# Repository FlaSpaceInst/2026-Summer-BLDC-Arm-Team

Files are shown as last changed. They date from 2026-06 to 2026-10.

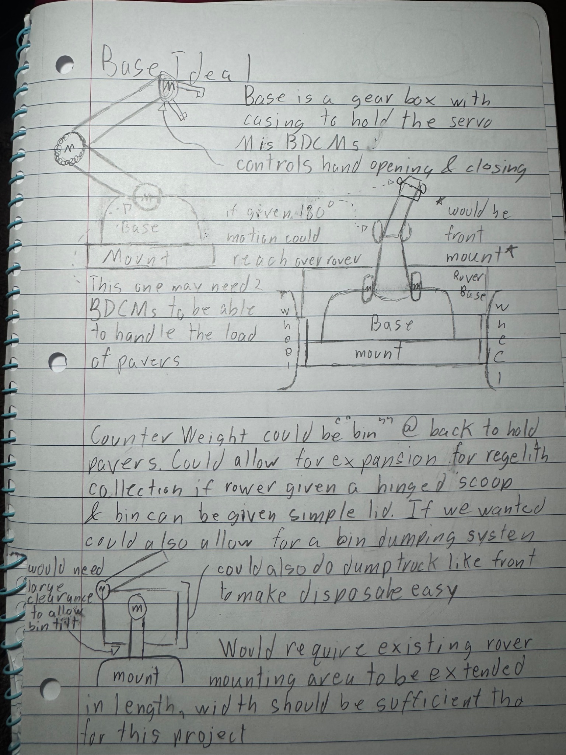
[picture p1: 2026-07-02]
Documentation & Testing/Misc. Design Artifacts/Rover Arm's Preliminary Design Sketch & Notes.jpeg

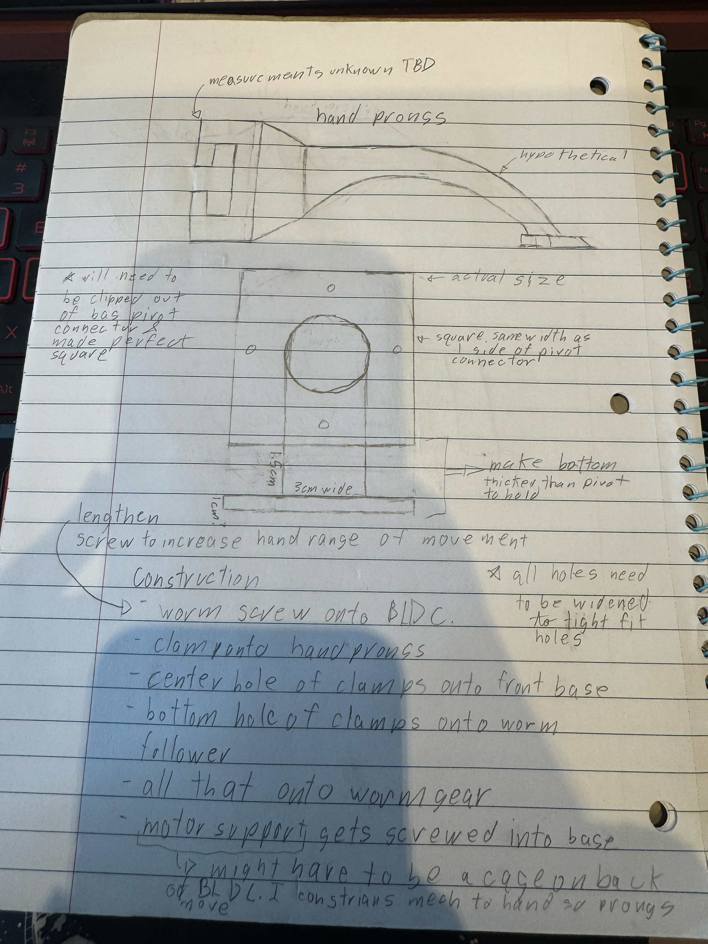
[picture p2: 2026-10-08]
Documentation & Testing/Misc. Design Artifacts/HandModificationEval.jpg

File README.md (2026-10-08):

# RE-RASSOR Arm Development

## Overview

The 2026 RE-RASSOR Arm Development Team is responsible for designing, prototyping, and integrating a modular robotic arm with the existing RE-RASSOR rover platform. The project builds upon previous RE-RASSOR Senior Design efforts while introducing new mechanical, software, and systems engineering capabilities focused on robotic manipulation.

The project has progressed beyond the preliminary design phase and is currently in the implementation, integration, and validation stage. The team has established the arm's primary mechanical architecture, developed and iterated multiple CAD prototypes, integrated inherited rover hardware and software resources, and continued development of the arm control interface and communication architecture.

The current arm design uses a four-degree-of-freedom configuration consisting of a rotating base, shoulder joint, elbow joint, and actuated end effector. The design uses a hybrid actuation approach incorporating a stepper motor for the arm base and BLDC motors for the upper arm joints. The BLDC motor platform builds upon work completed by the 2025 UCF BLDC Motor Control Team and is being evaluated for the different loading conditions introduced by the robotic arm.

Development is being performed iteratively through CAD modeling, additive manufacturing, assembly, subsystem evaluation, software development, and integration. Prototype revisions have been used to identify dimensional, structural, clearance, manufacturing, and assembly issues before progressing toward later versions.

In addition to developing the robotic arm, the project emphasizes documentation, maintainability, and knowledge transfer so future RE-RASSOR teams can continue development using the work produced during the 2026 project cycle.

---

## Project Background

The RE-RASSOR platform is a long-term educational and engineering project maintained through the Florida Space Institute (FSI) and supported by multiple University of Central Florida (UCF) Senior Design teams. The platform has undergone several iterations over multiple years, with each team contributing new capabilities, hardware improvements, software features, and documentation.

The 2026 RE-RASSOR Arm Development Team inherited an existing rover platform, control architecture, electrical systems, software resources, BLDC motor research, and previous design documentation. The current project therefore requires both new development and integration with systems that were not originally created by the 2026 team.

This repository serves as the development repository for the 2026 RE-RASSOR Arm Development Team and contains both inherited project resources and new development work completed during the Summer and Fall 2026 semesters.

---

## Acknowledgements and Prior Work

This project builds upon significant work completed by previous RE-RASSOR teams.

### 2023 RE-RASSOR Extension Team

The rover platform, base cart systems, software architecture, ROS integration, networking components, and core rover functionality contained within the **Base Cart & Control** directory originate primarily from the 2023 RE-RASSOR Extension Team.

Original repository:

https://github.com/FlaSpaceInst/2023-RE-RASSOR-Extension/tree/cart_desktop

The 2026 team did not develop the original rover platform and does not claim authorship of the inherited rover software, control systems, or base vehicle design.

### 2025 UCF BLDC Motor Control Team

The Brushless DC (BLDC) motor research, control systems, CAD resources, motor testing, and supporting documentation contained within the **BLDC CAD** directory originate from the 2025 UCF BLDC Motor Control Senior Design Team.

Original repository:

https://github.com/FlaSpaceInst/2025-Fall-UCF-BLDC-Motor-Control

The 2026 team utilizes this work as a technical reference and foundation for arm actuation development. The 2025 BLDC system was developed primarily for the rover wheel system; the 2026 project is extending its use to the robotic arm and evaluating its behavior under the different loading conditions associated with arm actuation.

The 2026 team does not claim authorship of the original BLDC motor project.

### 2026 RE-RASSOR Arm Development Team

The 2026 Senior Design Team is responsible for:

- Robotic arm design and development
- Arm integration with the existing rover platform
- New CAD models and prototype components
- Arm-related software modifications
- Arm control and user-interface development
- Testing and validation activities
- Documentation generated during the 2026 project cycle
- Future arm control functionality and user interface integration
- Integration of applicable inherited systems into the arm architecture

Unless otherwise noted, materials located within the **Arm & Attachments** and **Documentation & Testing** directories are the work of the 2026 RE-RASSOR Arm Development Team.

---

## Objectives

The primary objectives of this project are:

- Design and develop a robotic arm capable of manipulating the project's standardized 3D-printed pavers.
- Integrate arm controls with the existing RE-RASSOR control architecture.
- Utilize a hybrid stepper/BLDC actuation system appropriate for the arm's mechanical requirements.
- Prototype, evaluate, and iteratively improve the arm's mechanical components.
- Maintain compatibility with existing rover mechanical, electrical, and software systems.
- Develop an operator interface appropriate for multi-joint arm control.
- Establish testing procedures for mechanical, software, electrical, and integrated system evaluation.
- Maintain clear and reproducible project documentation.
- Produce deliverables that can be continued and expanded by future RE-RASSOR teams.

---

## Repository Organization

This repository contains inherited project resources as well as new development work produced during the 2026 project cycle.

### Base Cart & Control

Contains inherited rover resources originating primarily from previous RE-RASSOR teams, including:

- Rover software
- Control architecture
- Existing rover documentation
- Networking resources
- Base platform reference materials

Primary source:

https://github.com/FlaSpaceInst/2023-RE-RASSOR-Extension/tree/cart_desktop/ezrassor_rover/ros-scripts

### BLDC CAD

Contains inherited resources from the 2025 BLDC Motor Control Team, including:

- BLDC motor documentation
- Motor control research
- CAD resources
- Testing documentation
- Related design files

Primary source:

https://github.com/FlaSpaceInst/2025-Fall-UCF-BLDC-Motor-Control

### Arm & Attachments

Contains original development work produced by the 2026 RE-RASSOR Arm Development Team, including mechanical design, prototype development, manufacturing resources, and supporting documentation for the robotic arm.

#### CAD Files

Contains CAD resources developed throughout the project lifecycle.

**End Effector Designs**
- Gripper concepts
- End effector assemblies
- Attachment mechanisms
- Supporting design iterations

**STL & Development Files**
- Native CAD models
- Assembly files
- Prototype development resources
- Editable design files

**G-code & Printing Files**
- Printable STL exports
- Slicer projects
- G-code generated for prototype fabrication
- Manufacturing resources

### Documentation & Testing

Contains documentation produced throughout the project lifecycle, including:

- Design reports
- Design requirements and trade studies
- Testing procedures
- Validation results
- Meeting notes where applicable
- Research summaries
- Sponsor deliverables
- Development and integration documentation
- Records of design revisions and identified limitations

---

## Current Development Status

The project has progressed from preliminary design into active implementation and integration.

The primary mechanical architecture has been established as a four-degree-of-freedom robotic arm consisting of a rotating base, shoulder joint, elbow joint, and actuated end effector. Multiple prototype components have been modeled and fabricated through iterative CAD and additive-manufacturing processes. Prototype evaluation has identified and informed revisions involving dimensional accuracy, mounting interfaces, clearance, alignment, structural geometry, and manufacturability.

The arm's mounting system and base components have undergone multiple design iterations. The end effector has also undergone significant redesign following issues encountered during early prototype fabrication and assembly. These iterations are being retained as part of the project's engineering record to document both successful and unsuccessful design approaches.

Software development is progressing alongside the mechanical implementation. The team is extending the existing rover HTTP, ROS2, serial communication, and microcontroller architecture to support arm-specific commands while preserving existing rover functionality. Development of the arm user interface is also underway, including joint-level controls, arm visualization, camera integration concepts, and safety-oriented interaction mechanisms.

Current development efforts are focused on:

- Refining and fabricating mechanical prototype components
- Integrating the arm mounting system with the rover
- Evaluating the inherited BLDC motor platform under arm-specific loading conditions
- Completing arm communication and control pathways
- Developing and refining the robotic arm user interface
- Establishing reliable subsystem interfaces
- Performing mechanical, software, and integrated testing
- Documenting prototype failures, design revisions, and testing results
- Preparing the system for final validation

Some planned capabilities, including computer-vision-assisted target identification, ArUco-based target tracking, autonomous or semi-autonomous paver retrieval, interchangeable end effectors, and additional arm functionality remain future development priorities rather than completed baseline capabilities.

The remaining development effort will focus on subsystem integration, iterative testing, corrective design changes, and final system validation. Results from this work will be documented for continued development by future RE-RASSOR teams.

---

## License and Attribution

This repository contains a combination of inherited work from previous RE-RASSOR teams and original work created by the 2026 RE-RASSOR Arm Development Team.

Where possible, original sources have been referenced and credited. Users should review the source repositories and any associated licensing information before redistributing inherited materials.

Additional external design references used during development are documented in the project design documentation, including their applicable attribution and licensing requirements.

For questions regarding ownership or attribution of specific resources, consult the original repositories and source documentation referenced by this project.

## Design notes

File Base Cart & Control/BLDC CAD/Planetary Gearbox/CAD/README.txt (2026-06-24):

Gear Ratio: 3.76:1
CoPrime gear teeth numbers
custom 30 degree pressure angle

the purpose of using coprime teeth numbers and the steeper pressure angle is because these gears are intended for 3d print use, and both of these features have a measureable impact on the lifespan of 3d printed gearboxes.

Created by Nick Bernhoft in 2026

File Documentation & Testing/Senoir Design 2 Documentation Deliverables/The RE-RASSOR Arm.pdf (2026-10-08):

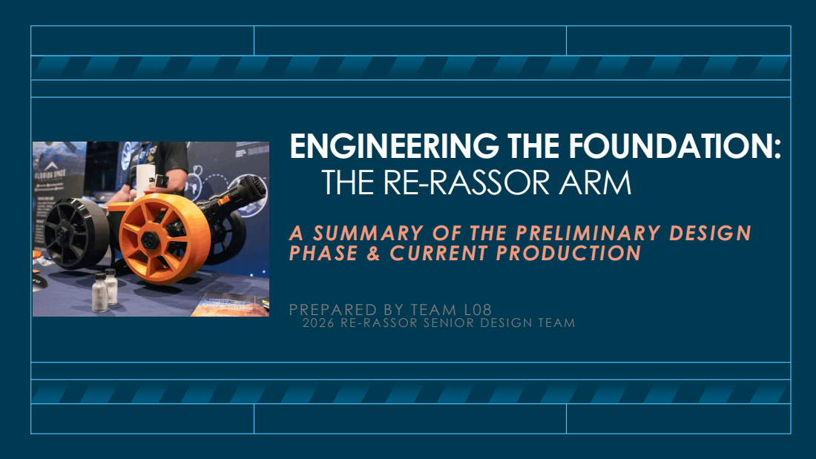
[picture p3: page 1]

ENGINEERING THE FOUNDATION:
THE RE-RASSOR ARM

A SUMMARY OF THE PRELIMINARY DESIGN
PHASE & CURRENT PRODUCTION

PREPARED BY TEAM L08
2026 RE-RA SSOR SE NI OR DE SI GN T E AM

2

Max | Tolu | Kaitlyn | Lucas | Nam
CAD Dev | CAD Dev | Project Manager | Software Dev | Software Dev

Responsibilities:
- Jira & Schedule
Management
- Assisting with CADing the center part of the arm &
counterbalance system +
printing responsibilities
- Initial Stretch Goal
Analysis

Responsibilities:
- Coding HTTP
Requests for the arm
- Integrating new
requests with
preexisting rover
control systems

Responsibilities:
- Coding the UI & API
for the arm
- Integrating new UI &
API with preexisting
rover control systems

Responsibilities:
- Designing &
CADing the arm's
base and
connection
mechanisms to the
existing rover
- Printing & Assembly
of Components

Responsibilities:
- Designing & CADing
the arm's end
effector and
grabbing mechanism
for the arm
- Printing & Assembly
of Components

Sponsored by The Florida Space Institute Funded by the Steven Hawking Center for Microgravity Research

# MEET THE TEAM

Problem 1:

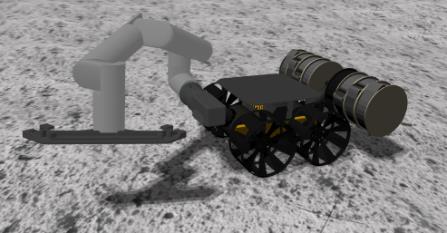
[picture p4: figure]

The Florida Space Institute is exploring 3D printing space craft and that requires initial prototypes to prove feasibility. Previous arm attempts have proven unsuccessful due to structural failure from heavy components and failed to mount onto the rover chasses.

Problem 2:

Due to the longevity of this project the documentation is scattered among 12 repositories and there is no singular source for all current working components.

3

# PROBLEM STATEMENTS

- Design a lightweight, modular robotic arm capable of manipulating standardized 3D-

printed pavers based off of our rover arm's of similar scale and function utilizing the

lighter brushless DC motor.

- Extend the existing software architecture through HTTP-based arm controls without

disrupting the rover's current control system.

- Produce comprehensive engineering documentation to support long-term

maintainability and knowledge transfer to future development teams.

- Organize as much of the existing documentation into our repository and the new

Florida Space Institute Onshape account to allow subsequent teams to pick up where

we left off

4

# OUR SOLUTION

- The Robotic Arm: must be mechanically capable of targeting, lifting, moving, and

precisely positioning the project's standard 3D printed pavers.

- Fully Realized 3D Assembly Models: STEP and .STL files detailing every link, joint,

bracket, and gear assembly of the robotic arm.

- Assembly Instructions: Step by step documentation detailing physical assembly,

fastener sizing, wire routing constraints, and maintenance requirements.

- Extension of Existing Software Architecture: Utilize the existing HTTP Request

architecture to allow our arm to be controlled by similar logic to the drivetrain

5

# REQUIREMENTS

Hardware:

- Printing Materials: PLA, PETG, Bambu X1-Carbon Printer
- Rover Components: BLDC/Stepper motors, Le Potato, Arduinos, BL Cooling Fan, Power Switch, 12.8V Battery, ArduCam
- Other Material Components: Netgear Router, Laptops

Software:

- Production: GitHub/Git, Arduino IDE, Android Studio, Visual Studio
- Libraries & Language: JavaScript, React, HTML, CSS, C++, Python
- CAD & Printing Software: Onshape, AutoCAD, Fusion 360, Bambu Studio

6

# TECH STACK

# THE DEVELOPMENT PLAN

Physical Rover Plan

- Discover failure points of the arms to figure out the core

design of our rover

- Front end designs and prints version 1 of arm in PLA. Then

tests and fixes our major failure points.

- Version 2 (where the project is currently at) is developed

and printed with PLA and final fixes are made after testing

- Final arm is printed in PETG & make final fixes

Software Plan

- Condense the previous 12 GitHub Repositories to get the

scope of the current HTTP request and UI design

- Requests and UI are designed simultaneously to the physical

rover and tested where possible on the prototypes

7

# THE JIRA

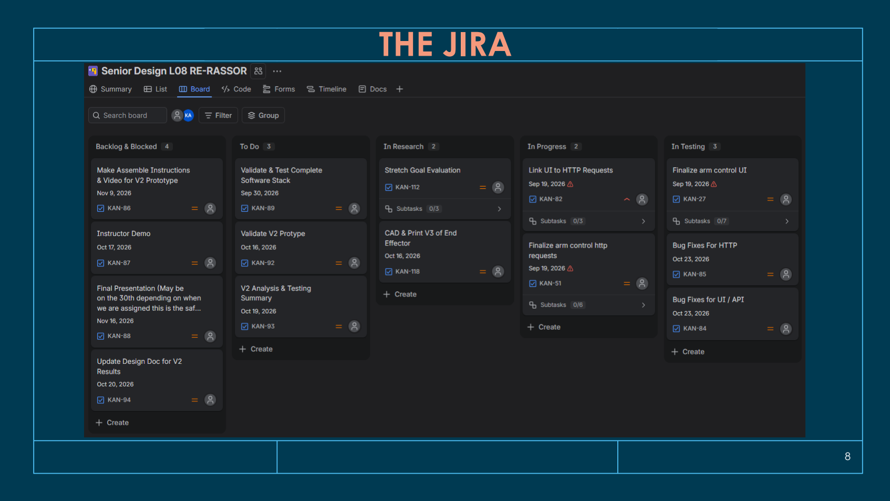
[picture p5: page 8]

8

# USE CASE DIAGRAM

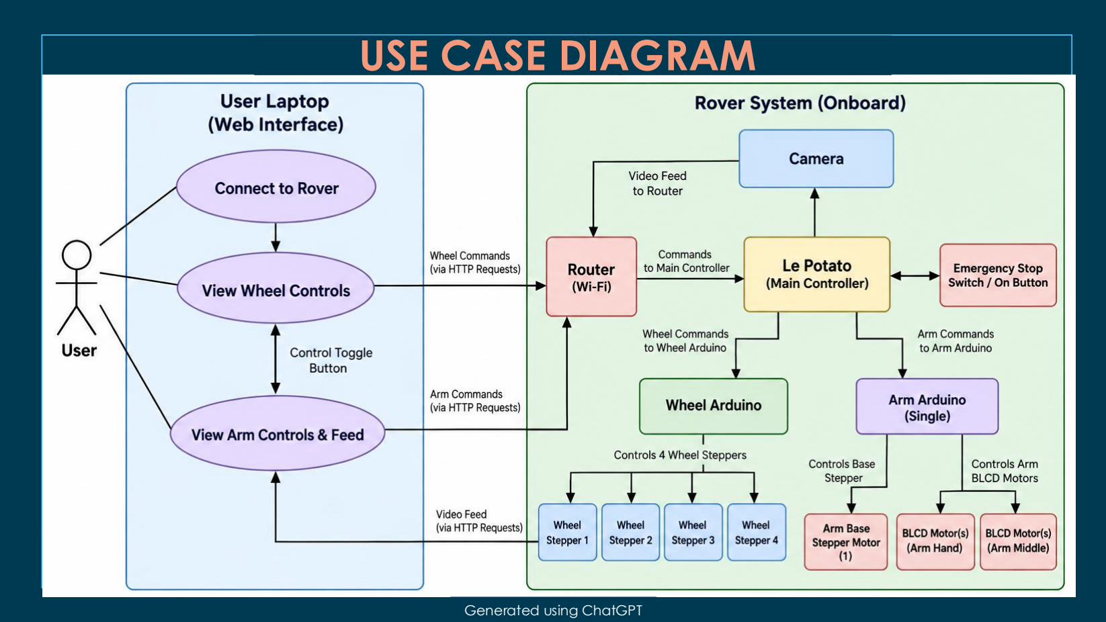
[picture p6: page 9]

9

Generated using ChatGPT

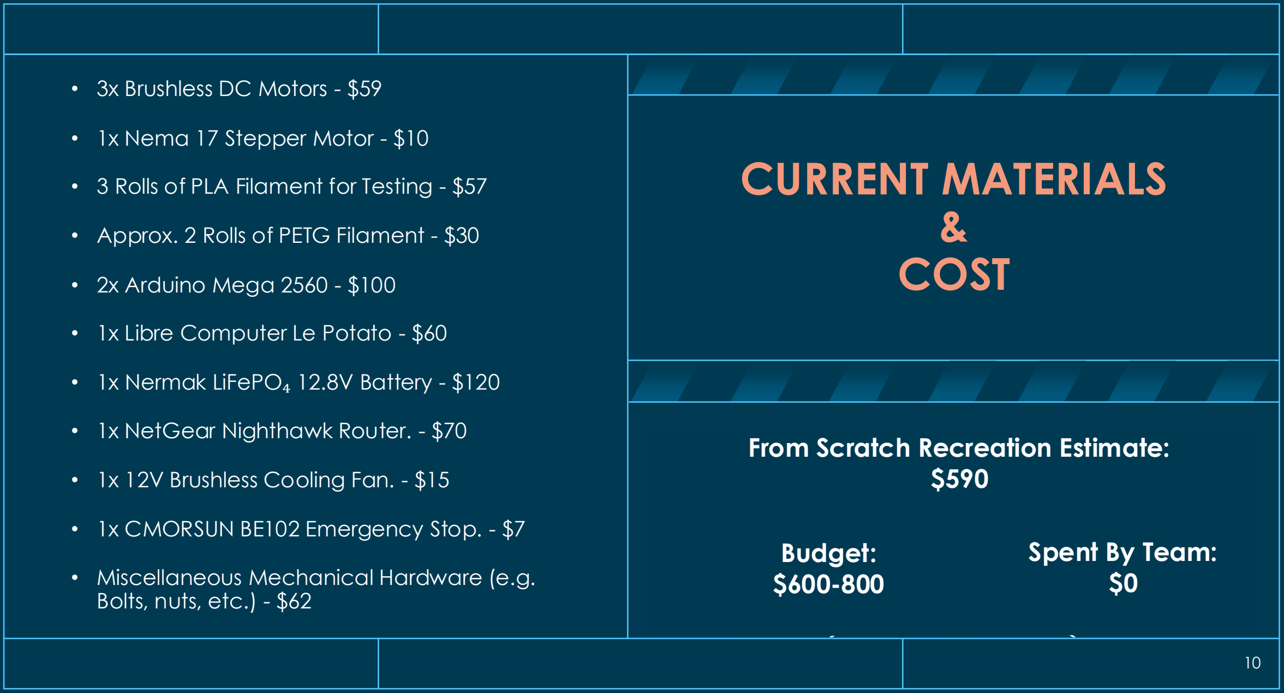
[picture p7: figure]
CURRENT MATERIALS & COST; • 3x Brushless DC Motors - $59; • 1x Nema 17 Stepper Motor - $10; • 2x Arduino Mega 2560 - $100; • 1x Libre Computer Le Potato - $60; • 1x NetGear Nighthawk Router. - $70; • 1x 12V Brushless Cooling Fan. - $15; • 1x CMORSUN BE102 Emergency Stop. - $7; • Miscellaneous Mechanical Hardware (e.g. Bolts, nuts, etc.) - $62; Spent By Team: $0; From Scratch Recreation Estimate: $590; Budget: $600-800

- 3 Rolls of PLA Filament for Testing - $57
- Approx. 2 Rolls of PETG Filament - $30
- 1x Nermak LiFePO₄ 12.8V Battery - $120

DESIGN | DECISION | MATRIX

11

Design Decision | Alternatives | Engineering
Considerations | Final Selection
Actuation | Stepper / Servo / BLDC | Weight, torque, integration, efficiency

## Majority BLDC With a Stepper Base

Arm Location | Front / Rear / Center Mount | Stability, workspace,
compatibility | Front
Communication HTTP / Serial / ROS | Existing infrastructure,
simplicity | HTTP
Printing Material | PETG / PLA | Cost, safety, heat resistance

## PETG for Final PLA to Test

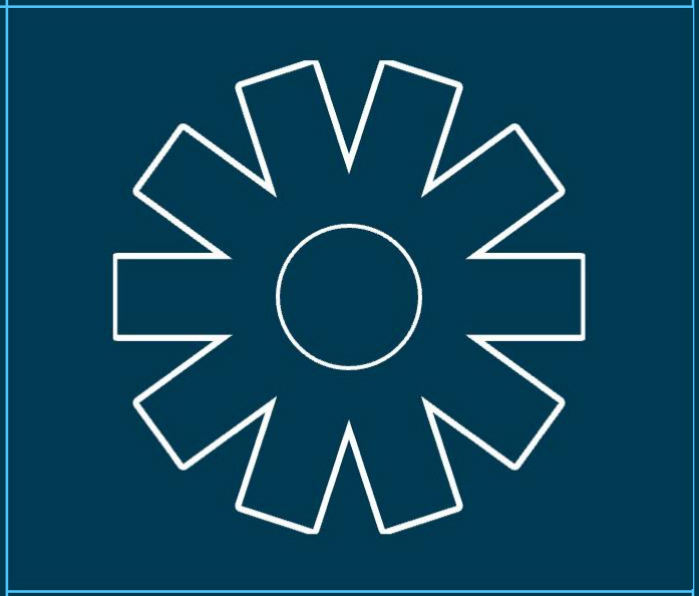
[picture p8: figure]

# OUR STATUS REPORT & SUCCESSES

- The central part of the arm is complete and thus far appears to work with the brushless DC motors upon physical manipulation
- The base of the arm is nearly complete with minimal changes needed
- Final initial CAD mock up of the arm is complete and in printing/testing
- The current printed and assembled components have no weight conflicts with the rover resulting in smooth on-rover assembly
- HTTP requests have been drafted and are in testing
- UI is complete with API being developed

12

# THE CURRENT ROVER

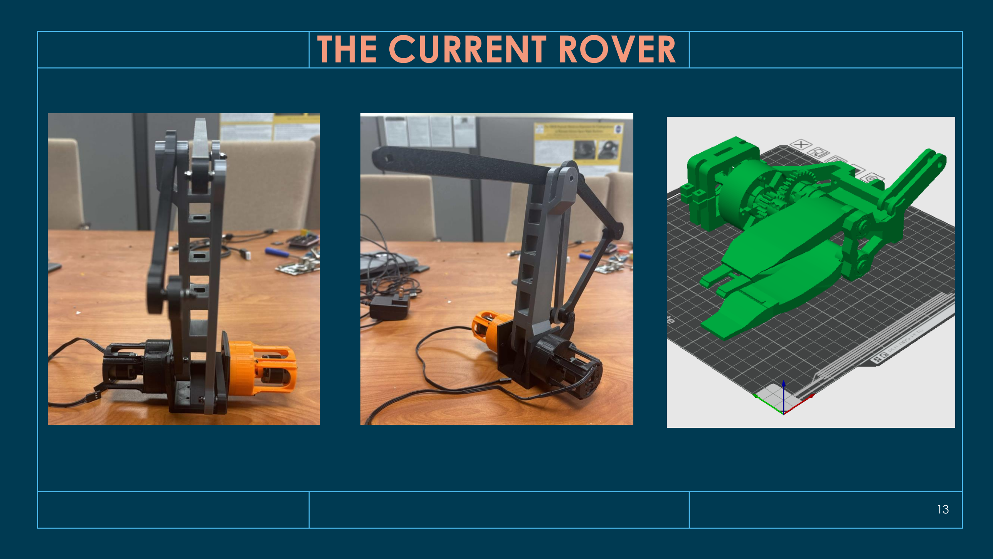
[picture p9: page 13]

13

14

# CURRENT UI

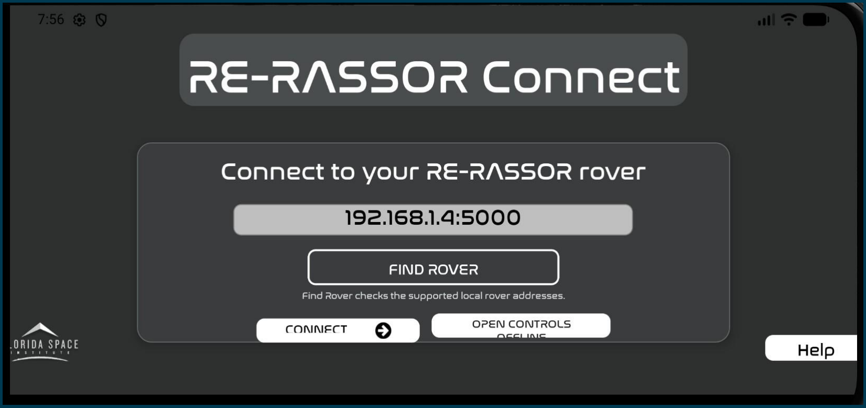
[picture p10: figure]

15

CURRENT UI CONT.

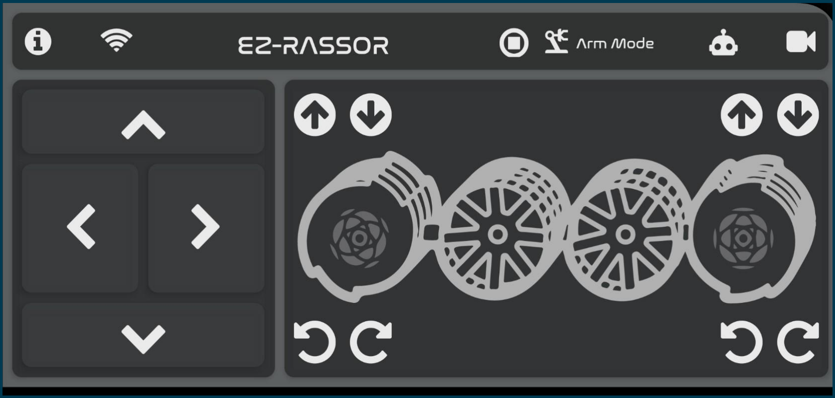
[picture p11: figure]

CURRENT UI CONT.

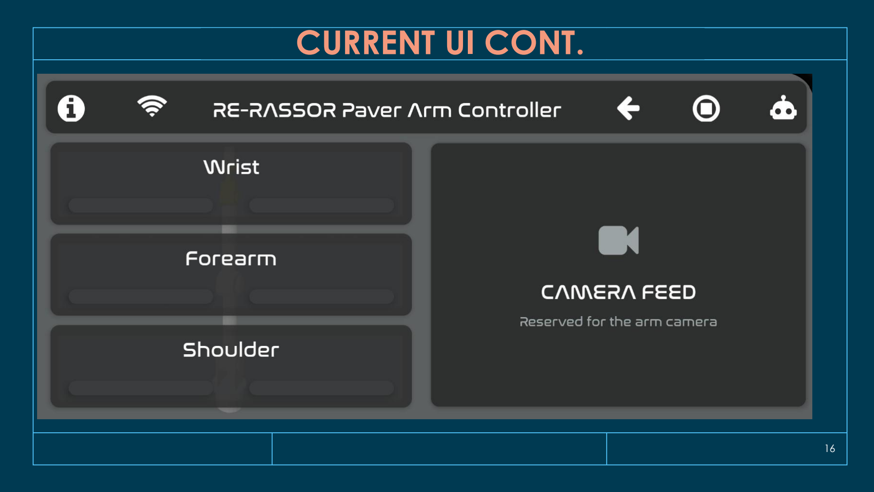
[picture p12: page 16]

16

CURRENT | HTTP | REQUESTS
- The current system has 2 major forms that commands can take on while being passed around:
- HTTP messages containing JSON stringified objects
- Enumerations
- Enumerations are primarily used within the Potato and Arduinos on the rover, while HTTP messages and the corresponding JSON objects are primarily used by the control app to communicate with the rover.
- For example, if the operator chooses to stop the end effector, the corresponding JSON object would be stringified as "{'end_effector_action':'STOP'}" and would be posted to the rover in its own HTTP message.
- This would correspond to the STOP_EFFECTOR command, enumerated as hexadecimal byte 0x0B.

17

18

## - The end effector has been complex to design and thus has taken longer to develop than expected

## - Overall project complexity was more difficult than expected with a primarily software foundation on hardware project

- Lack of documentation resulted in a steep learning curve for any existing rover features

## and resulted in initial development delays

## - A variety of communication styles and personalities has made organizing and communicating difficult and required a learning curve

# OUR CHALLENGES

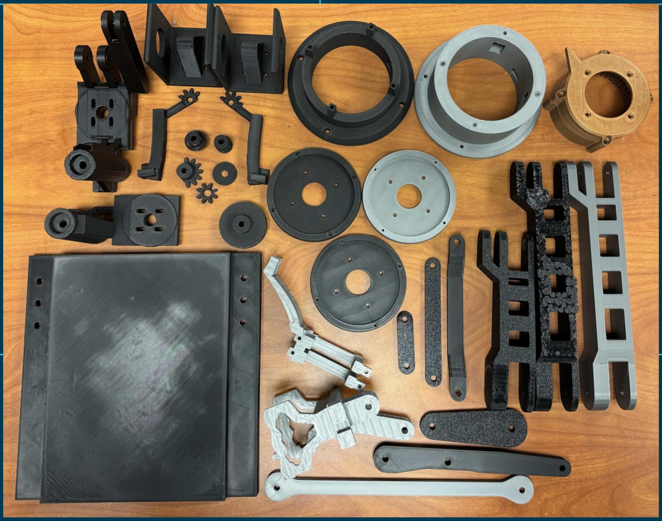
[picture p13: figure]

# THE FAILED PROTOTYPES

Common Causes of Error Include:

- Changes to V2 that resulted in multiple components needing redesign
- Incorrect supports leading to printing issues and difficult to remove components that required redesign
- The printer warping screw holes making exact mechanical connections require multiple adjustments

19

# TOP STRETCH GOALS

- Feasibility Exploration Status: Complete
- Dev / Code Location: PM Branch
- Description:
- Rover uses the Ultralytics YOLO26 Nano
(YOLO26n) model for preliminary item search via the camera and a combination Lucas-Kanade + Canny Algorithm for target tracking after item selection

20

Semi-Autonomous
Item Identification & Retrieval
- Feasibility Exploration Status: To Be Assigned &Complete
- Dev / Code Location: Main / Relevant Member's Branch
- Description:
- Some lunar rover tasks such as regolith collection are not possible with our base rover arm designs. Interchangeable options would enable future teams to build off our work.

Interchangeable End Effectors

# QUESTIONS?

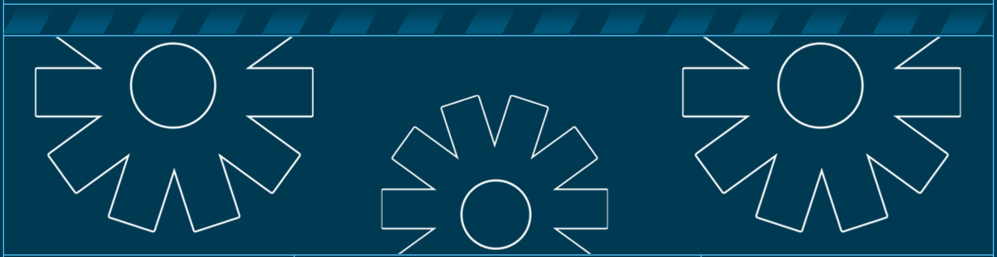
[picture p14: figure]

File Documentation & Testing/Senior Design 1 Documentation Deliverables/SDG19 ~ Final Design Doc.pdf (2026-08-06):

# RE-RASSOR 2026

# Design Document

### Prepared by Group 19:

Kaitlyn Armstrong, Nam Dang, Toluwalope Elugbaju,

Max Grabov, & Lucas Marrou

### Sponsored by the Florida Space Institute

### Funded by the Stephen Hawking Center for Microgravity Research

### University of Central Florida

Department of Computer Science – Senior Design 1 – Summer 2026

Submitted: August 2, 2026

## 2026 RE-RASSOR Final Design Document

# Table of Contents

Management Considerations | 65 Initial Feasibility Analysis | 65 Initial Considerations of Stretch Goals & Feasibility | 66 Autonomous Object Pickup | 66 Additional Wrist Joint for Rotation | 67 Interchangeable End Effector Attachments | 67 Camera Integration into End Effector | 68 Complex Counterweight System | 69 User Interface Design Alterations for Precise Control | 69 Strech Goal Prioritization | 72 Suggested Long-Term Development Roadmap | 73 For More Information on Our Considerations of Users During Our Design See the Administration Section of this Document | 74 Design Diagrams & Descriptions | 75 Use Case Diagram | 75 Activity Diagram | 76 Block Diagram | 77 Component Modifications Made During Development | 78 The Mounting Plate | 78 The Arm Base | 79 The Arm Base Pivot Connector | 82 Planned Modifications to the User Interface | 84 Conclusions | 87 Where We Fell Short | 87 Initial Timeline Issues | 87 Administration | 88 Budget & Material Procurement | 88 Current Cost Breakdown | 89 Arm Cost Table | 89

Rover Body Cost Table | 89 Printing Time Breakdown | 90 User Stories | 91 Rover Operator from a User Perspective | 91 Rover Operator from a System Administrator Perspective | 92 Future RE-RASSOR Development Team | 92 FSI Sponsor | 92 Development Team Member | 93 Researcher | 93 Summary of Current Completed Tasks and Subtasks | 93 Jira Workflow | 95 Acknowledgements | 96 Project Guidance | 97 Institutional Resources | 97 Appendix | 98 Previous RE-RASSOR Projects | 98 Internal Documentation | 98 Hardware Documentation | 99 Software Documentation | 99 Design Inspiration | 100 Robotics & Technical References | 100 Manufacturer Datasheets | 101 Project Methodology | 101

# Executive Summary

The RE-RASSOR Arm Development project is a collaborative senior design effort sponsored by

the Florida Space Institute (FSI) to expand the capabilities of an existing RE-RASSOR rover platform

through the design, fabrication, and integration of a robotic manipulator. Previous iterations of the rover

have successfully demonstrated autonomous mobility and excavation capabilities; however, the platform

currently lacks a manipulator capable of interacting with its environment. The objective of this project is

to develop a multi-degree-of-freedom robotic arm that can be mechanically integrated with the existing

rover while utilizing the current software architecture and communication framework.

The project encompasses the complete engineering design process, including mechanical design,

additive manufacturing, software development, electrical integration, and system testing. Mechanical

components are being modeled using AutoCAD and fabricated through additive manufacturing to enable

rapid prototyping and iterative refinement. Existing rover hardware and software are being leveraged

whenever possible to minimize redevelopment while maintaining compatibility with the established

control system. The software architecture will be extended through additional HTTP-based

communication interfaces that allow independent control of each arm joint while preserving the modular

design of the current rover application.

To reduce technical risk, the project follows an incremental development strategy in which

individual subsystems are designed, validated, and integrated before full-system testing. Mechanical

prototypes are evaluated for fit, structural integrity, and compatibility with the rover platform prior to

final fabrication, while software components are developed and tested independently before hardware

integration. This iterative approach enables design improvements to be incorporated throughout the

project while reducing integration challenges during later development stages.

Upon completion, the robotic arm will provide the RE-RASSOR platform with enhanced

manipulation capabilities, enabling future research into autonomous interaction with extraterrestrial

environments. The final system is expected to serve as a modular platform that future senior design teams

and researchers can continue to expand, supporting the Florida Space Institute's ongoing development of

robotic systems for planetary exploration and other remote operation applications.

# Introduction

## What is RE-RASSOR?

The Regolith Excavation – RASSOR (RE-RASSOR) platform is a long-term multidisciplinary

robotics project sponsored by the Florida Space Institute (FSI) and supported by the Stephen Hawking

Center for Microgravity Research at the University of Central Florida. Rather than being a standalone

senior design project, RE-RASSOR represents the continued development of an educational and research

platform that has been expanded over multiple years by successive teams of students.

The rover is derived from NASA's RASSOR (Regolith Advanced Surface Systems Operations

Robot) concept, which was developed to investigate autonomous excavation and material handling for

future lunar and planetary exploration missions. While the original NASA platform was designed for

large-scale excavation using dual counter-rotating bucket drums, the Florida Space Institute's

implementation serves as a smaller, modular research platform that enables students to explore robotics,

autonomous systems, software engineering, mechanical design, additive manufacturing, and systems

integration within a realistic engineering environment.

Unlike projects that begin with a blank slate, RE-RASSOR follows a continuous development

model. Each senior design team inherits the hardware, software, documentation, and lessons learned from

previous teams before contributing to new capabilities for future development. This iterative approach

mirrors many real-world engineering programs in which complex systems evolve through incremental

improvements rather than complete redesigns. Consequently, maintaining compatibility, producing high-

quality documentation, and designing modular systems are considered just as important as developing

new functionality.

Over the past several years, previous teams have steadily expanded the platform's capabilities.

Earlier teams established the rover's mechanical foundation, developed the software architecture,

implemented ROS2 communication, created a web-based control interface, redesigned the drivetrain

using brushless DC motors, and improved the manufacturability of the overall platform. These

accomplishments provide the foundation upon which the current project is built.

The focus of the 2026 RE-RASSOR project is to extend the existing rover by designing,

manufacturing, and integrating a robotic manipulator capable of interacting with objects in its

environment. This robotic arm will enable the rover to grasp, transport, and accurately position standardized 3D-printed pavers while remaining compatible with the existing mechanical structure and

software architecture. Beyond providing new functionality, the project emphasizes modularity,

maintainability, and comprehensive documentation so that future student teams and researchers can

continue expanding the RE-RASSOR platform with minimal redevelopment effort.

Ultimately, RE-RASSOR serves two complementary purposes. As a research platform, it enables

experimentation with robotic systems intended for remote and extraterrestrial environments. As an

educational platform, it provides students with experience working on multidisciplinary engineering

projects that integrate mechanical design, embedded systems, software development, additive

manufacturing, systems testing, and long-term project maintenance. The work completed by each team

becomes the foundation for the next, ensuring that the platform continues to mature through successive

generations of student engineers.

## Deliverables & Objectives

The main objective of our team is to design, build, test, and deliver a fully functioning, scaled robotic arm

that integrates with the existing RE-RASSOR rover platform. As this project is built on multiple years of

earlier student development, our baseline objectives are heavily weighted toward developing a solid,

physically reproducible mechanical design while building out the web-based software framework to drive

the arm.

### Minimum Viable Product

To fulfill our contract, the completed system must achieve the following milestones:

Physical Manipulation Capabilities

The robotic arm must be mechanically capable of autonomously or manually targeting, lifting,

moving, and precisely positioning the project's standard 3D printed pavers. These pavers weigh under one

pound with diverse shapes and sizes. The arm must execute these tasks without causing structural

deformation to itself or the rover’s chassis.

Rover Stability Maintenance

An important performance objective is that the arm must operate within its specified envelope

without causing the RE-RASSOR rover to flip, tip, or lose traction. Because the base body of the rover

(excluding wheels, lid, and electronics) has a relatively low mass because it is primarily constructed from lightweight PETG. Any extension of the arm shifts the center of gravity drastically. The arm’s weight and

motion profile must be balanced to maintain steady operations.

Control System Integration:

The rover control system must be easy to set up, visualize, understand, and use. And must

incorporate arm control systems together seamlessly with the rover’s base control system without causing

system to back up or reduce performance.

### Detailed Technical Deliverables

When the project is finished, the team will give the sponsor a complete handover package. This

package, which is divided into four different categories, guarantees complete continuity for upcoming

student teams:

Computer Aided Design (CAD) Packages

Fully Realized 3D Assembly Models: Complete. STEP and .STL files detailing every link, joint,

bracket, and gear assembly of the robotic arm.

Rover Modification Models: CAD files detailing the exact geometry of any custom

supplemental mounting plates or counterweight brackets affixed to the rover body.

Software and Firmware Source Code

Web Interface Upgrades: Clean frontend code integrated into the existing web application UI

that features intuitive controls for managing the arm's multi axis movements seamlessly alongside

the primary drive controls.

HTTP Endpoint Registry: Well documented backend application routes managing incoming

HTTP requests assigned to arm actuation.

Low Level Motor Control Logic: Optimized C/C++ Arduino sketches managing the distribution

of pulse width modulation (PWM) or serial commands to the custom Brushless DC Motors

(BLDCM) and tracking rotary feedback. All of the source codes will be securely tracked across

the designated GitHub branches.

Fabricated Physical Hardware

Functional Arm Assembly: A fully manufactured 3D printed mechanical arm primarily

composed of PETG plastic to provide structural endurance against environmental heat loads.

Electromechanical System: An integrated suite consisting of lightweight Brushless DC Motors,

associated gear reduction units (such as cycloidal or worm gearing), complete power wiring

harnesses, and local network microcontrollers.

Engineering Documentations

Assembly Instructions: Step by step documentation detailing physical assembly, fastener sizing,

wire routing constraints, and maintenance requirements.

Verification and Validation Reports: Documented logs of unit tests, full system integration

checks, and formal acceptance testing witnessed by the project sponsor.

Future Work Backlog: A clear record of failed design iterations, lessons learned, and

recommended improvement tracks for subsequent teams.

## Impact of Our Project

Possible Effects on Research

A working rover arm would give future teams a usable starting point for experiments. They could

study how the arm behaves on a light mobile base, then compare later changes against the same setup.

This matters because each new team currently spends part of its schedule learning the inherited rover and

rebuilding missing knowledge. A complete arm, supported by clear files and test records, would move

that work forward. Later groups could begin with a known assembly and focus on a specific question such

as joint accuracy, payload limits, or rover stability during movement.

The arm also creates a useful test case for the brushless DC motors developed for earlier RE-

RASSOR work. Those motors were designed for the rover drivetrain, where the load stays close to the

chassis. The arm places them in a more demanding arrangement. A motor at the shoulder must move the

links and every component mounted past that joint. Measurements from loaded lifts would show how

much gear reduction is needed and how the motors respond after repeated cycles. Results from these tests

could guide later motor selection without forcing each team to repeat the same basic evaluation.

Additive manufacturing gives the project another research value. Printed arm parts can be

adjusted quickly after a fit issue or structural weakness is found. Each revision can be tied to a specific

observation from testing. A team might change the wall thickness after a mount flexes, then compare the

revised part during the same lift. Keeping the failed part and recording the conditions that caused the problem would produce evidence that later teams can use. Over time, the project could build a practical

record of how printed components behave in a small robotic manipulator.

Operation of the arm may also support research on user control. The rover already uses a remote

interface, and the new controls will place driving and manipulation in the same system. A new operator

can reveal problems that the development team may overlook. Hesitation during a pickup task may point

to an unclear label or an awkward control layout. Camera feedback could be studied in the same way once

a view near the gripper is available. These observations would help future teams improve the operator

experience without changing the pickup task used for evaluation.

Possible Effects on General Populous

The project is most likely to affect the public through education. RE-RASSOR gives students a

physical example of code controlling a machine. A command on the screen causes a motor to move,

which then changes the position of the arm. This connection is easy to see during a demonstration and can

make robotics feel less abstract. The paver task is also simple enough for an audience to follow without a

long technical explanation. Students can watch the rover approach an object, pick it up, then place it

somewhere else.

Demonstrations can also show how engineering work develops. Finished products often hide the

failed prints and revisions that came before them. RE-RASSOR offers a chance to show those steps. A

part may fit poorly during the first print, or a joint may loosen after repeated movement. The team then

measures the problem and changes the design. Showing that process gives students a more accurate view

of engineering. It also makes failure easier to understand as useful information is gathered when the team

records what happens. This information can then be used during the next revision.

The rover may help generate interest in space related robotics because its task can be connected to

work performed in remote environments. Paver handling can represent a small version of moving

construction material or positioning equipment. Its purpose is to make engineering questions visible.

Students can see why weight matters when the arm extends and why communication problems become

serious once software controls moving hardware.

Schools and robotics clubs could use the design after the project files are organized for reuse. A

group with access to a suitable printer may build selected components or create a smaller classroom

version. They may also use the existing arm as a base for a project focused on one attachment. This

lowers the amount of work needed for a short project. The usefulness of the files will depend on the

instructions that accompany them.

Access will still vary between schools. Some programs may lack a printer that can produce larger

parts. Some programs may also lack a mentor who is comfortable working with motors and batteries. The

documentation should state the equipment required and explain which tasks need close supervision.

Simplified activities could help groups that cannot build the complete rover. A student might study the

gripper on a fixed stand or use the CAD files to design a compatible attachment. These smaller uses

would still support the educational goal of the project.

Other Uses of Our Rover and Arm Addition

The arm gives RE-RASSOR the ability to interact with objects around the rover. Paver pickup is

the required demonstration, though the same movement can support several classroom activities. One

example is a sorting course. Printed objects could be placed in marked areas, and the operator would

move each one to a matching location. The task could begin with manual control. A future team could use

the same course after adding visual markers or a simple detection program.

A camera near the gripper would allow the arm to serve as a mobile inspection tool. The operator

could position the camera close to a test part or a location that is difficult to view from the main rover

camera. This use places little demand on the gripper because the arm would mainly hold the camera in

position. It could be useful during troubleshooting as well. A close view of a joint or printed component

may help the team observe movement that is difficult to see from outside the test area.

The end of the arm could support tools made for specific lessons. A scoop would allow small

amounts of simulated regolith to be moved during a demonstration. A probe could touch marked points as

part of a positioning exercise. A tray could carry a light object across a short course. Each tool would

need to stay within the tested load of the arm. A standard attachment point would make these projects

easier because students could work on the tool without changing the rest of the mechanism.

Feasible Uses

Manual paver manipulation is the clearest use supported by the current design. The operator

would drive the rover into position through the existing interface. Arm controls would then move the

gripper toward the paver. A successful sequence ends when the paver is lifted and placed at the target.

This task gives the team a direct way to evaluate the design because every subsystem must work together.

The rover must remain stable during the lift, and the gripper must hold the object until release is

commanded.

The rover can also support supervised robotics lessons using the software path already planned

for the arm. Students can observe how an input moves through the application and reaches the motor controller. Logs can be used to show what happens when a request is accepted or rejected. This gives the

demonstration of a software component without requiring students to operate the physical rover

immediately. Once the command path is understood, they can connect it to the motion they see during a

controlled test.

A documented end effector connection is practical within the current project. The gripper already

needs a secure connection to the wrist. Defining that connection with fixed measurements would allow

later teams to make new tools that fit the same arm. The mechanism should remain simple enough to print

and assemble with common hardware. A screw-based plate or keyed connection could meet that goal.

Testing would confirm that the attachment stays rigid during a paver lift.

Camera assisted operation is also realistic if the first version only provides a live view. A small

camera placed near the end effector could help the operator line up the gripper with the paver. The video

would also make failed pickup attempts easier to study because the team could see the contact point. The

camera mount would need to stay clear of the fingers and the ground. Its wiring would also need enough

movement to follow the arm without being pinched.

Stability testing may show a need for rear weight. A fixed counterweight or small storage area

could be added with limited design work. The amount should come from testing with the arm extended.

Too much weight could reduce mobility and add stress to the rover. A measured solution would provide

rear support without making normal driving impractical. An active balancing system would require more

development than the current stage allows.

Theoretical Uses

A more advanced version of the rover could support automated placement of standardized

building pieces. The current pavers provide a small-scale example of that type of work. A future system

would need to detect each piece and determine where it should be placed. It would also need dependable

rover positioning, so the arm begins each movement from a known location. The present project cannot

provide that level of accuracy, though it can establish the mounting and control structure that later work

would need.

Regolith handling is another possible direction for the arm. A scoop or sample container could

allow a future rover to collect material from a test area. The material could then be moved to a storage

location or delivered to another device. Real field use would place much greater stress on the joints than

the current paver task. Dust would also affect bearings and printed gearboxes. Work in this area would

require protective changes and stronger validation under simulated environmental conditions.

Several rovers could eventually cooperate on a larger task. One rover might carry material. A

second rover could handle placement. Their software would need a shared understanding of location and

task status. The rovers would also need a way to recover when one unit stops or loses communication.

This direction could turn RE-RASSOR into a platform for studying coordination between mobile robots.

It would require a dependable single rover before multi rover behavior could be evaluated in a useful way.

Remote maintenance could become possible with a more precise arm and a specialized tool. A

future rover might press a switch or reposition a small instrument. Some tasks could require the arm to

connect to a cable, remove a cover, or other tasks that require precision. These actions require accurate

depth information and much tighter control than paver pickup. Force feedback would also be needed to

prevent damage when the tool contacts equipment. The current modular end effector goal could give later

teams a place to begin experiments in this area.

The rover could also carry sensors into locations that are difficult to inspect from a fixed camera.

The arm could position a depth sensor close to the surface. The rover could remain at a safe distance

during the measurement. A future system might recognize an area of interest and move the sensor into

place automatically. This would combine mobility with controlled sensor placement. The arm would need

better position feedback before measurements could be tied to a precise location.

These uses describe possible development paths. The current prototype is only an early step

toward those capabilities. Their purpose in this document is to show how decisions made now may affect

later work. A rigid wrist interface and organized control code would make expansion easier. Poorly

documented dimensions or unclear software dependencies would make the same ideas much harder to

pursue.

## Implications & Ramifications Associated with Our Project

### Legal Implications

The RE-RASSOR arm is being developed as a university teaching and research prototype. Its

legal concerns are limited at this stage, though the team still needs to handle reused work correctly. The

project draws from earlier RE-RASSOR repositories and from the EEZYbotARM design. Credits and

license notices should remain with any files that require them. The final repository should also make clear

which parts were created by our team and which parts were adapted from earlier work.

Publicly available designs may still include conditions for reuse. A file may allow modification

and still require attribution. It may also restrict how a copy is distributed. Future teams should be able to

find this information without searching through old repositories. Our documentation should identify the source of major reused components and preserve links to the original work. This protects the contributors

and reduces confusion if the project is shared.

Liability becomes more relevant during demonstrations. The arm has moving joints that can

create pinch points. An extended arm could cause the rover to tip. Operations should remain supervised

and should stay within the limits established during testing. The team should provide an inspection

process for the person running the demonstration. Warnings should also be included for any area where a

hand could come into contact with the mechanism.

Privacy concerns are limited in the current design because a camera is not required for the

baseline arm. Camera integration may be explored later as a stretch goal to improve operator visibility or

support object detection. Any future implementation should avoid unnecessary recording and follow UCF

or host organization policies when video is saved.

Laboratory and event policies will continue to apply to the rover. Battery handling must follow

the rules of the facility where the system is tested. The same is true for printer use and electrical changes.

A future commercial version would require a much broader review of product safety and data practices.

The current team should describe only the standards and limits that have been evaluated.

### Ethical Implications

Our main ethical responsibility is the safety of anyone near the rover. The arm is small enough for

a classroom lab, yet an unexpected movement can still catch a finger near a joint. Testing should begin

with individual components before the complete arm is powered. A fixed stand gives the team a safer

place to identify binding or uncontrolled motion. Full rover tests should begin only after the stop

command and emergency shutdown have been verified.

The team should describe the system honestly. The project draws from ideas used in planetary

robotics. The prototype itself remains a supervised classroom platform. A successful paver lift should be

reported as one defined manipulation task completed under known conditions. Clear limits make the

project more credible and help future students understand what still needs to be solved.

The educational goal also requires a simple and intuitive control mechanism and detailed

documentation that is understandable to people outside the team. Internal names may make sense during

development but confuse a new operator. Labels should describe the physical movement they cause.

Assembly instructions should explain each step without assuming that the reader attended our meetings.

This helps future teams use the system safely and gives more students a reasonable chance to learn from

the project.

We also have a responsibility to preserve the work that came before us. Earlier teams produced

code and mechanical ideas that made our project possible. Their contributions should remain credited in

the final files. Our own failed parts should be documented with the same care as the successful versions.

Deleting that history would make later teams repeat problems that we have already observed.

Autonomous movement would create additional ethical concerns because the rover would begin

making decisions from sensor input. A detection error could send the arm toward the wrong object. Future

automated modes should keep a human operator ready to stop the system. Motion limits should be

conservative until repeatability has been demonstrated. The camera should focus on the task area and

collect only the information needed for operation.

Material use is part of responsible development as well. Some failed prints are expected during

prototyping. Careful measurements and fit checks can keep the amount reasonable. Reusable fasteners

should be recovered when a design is retired. Slicer settings that produce a strong part should be recorded

so later teams can begin with a proven setup. These habits support the teaching purpose of the project

because they show that engineering decisions affect resources as well as performance.

Privacy & Security and Its Relation to this Project

Privacy and security are secondary concerns for the current RE-RASSOR arm because it is a

supervised teaching system on a local network. The rover handles control commands and camera data, not

sensitive personal records. The more immediate risk is physical movement caused by an incorrect

command. Basic security still matters because any device connected to the rover can potentially influence

that movement. The level of protection should match the classroom setting and the actual risk of the

prototype.

The rover should operate through the dedicated router used by the project. Access should be

limited to approved devices during testing. The router should use a changed password, and the setup

instructions should tell future teams where that password belongs without placing it in the public

repository. The server should validate every arm request before it reaches the motor controller. Joint

values outside the tested range should be rejected. Loss of communication should also cause motion to

stop.

If recording capability is added later, any saved footage should have a clear purpose tied to

testing or documentation. The files should be stored in an approved location with access limited to the

project team. Project repositories also need basic security. Passwords and private keys should stay out of

GitHub. Local network addresses should remain in setup notes. Example configuration values can show

future teams how the system works without exposing active credentials.

## Meet the Team

This section contains statements from our team collected at the beginning of this project. Each member

summarized their previous experiences, reasons for ranking this project highly in the assignment process,

personal motivations for the project, and hopes for what could be accomplished

### Kaitlyn Armstrong

I am excited to be working on the RE-RASSOR Arm Development project because it combines

several areas that have interested me for many years, including robotics, software development,

engineering design, and project leadership.

My interest in robotics began in high school through the FAU Robotics League and the FIRST

Robotics Competition (FRC), where I gained experience working on multidisciplinary engineering teams

and developing solutions under strict deadlines. During that time, I not only worked on the hardware and

software of metal channel robots but also served as Lead Programmer and Co-President of my high

school's team. These experiences exposed me to both the technical and organizational aspects of robotics

projects and taught me the importance of communication, planning, testing, and documentation when

working on complex systems.

Beyond the technical experience I gained through robotics, I am also excited about the

educational impact of projects like RE-RASSOR. My own interest in engineering and computer science

began in middle school through LEGO Robotics, which introduced me to programming and problem-

solving in a hands-on environment. That experience ultimately played a significant role in my decision to

pursue a degree in Computer Science. Because of that, I appreciate projects that can inspire future

students in the same way and want to provide other young individuals with avenues to inspiration like

what LEGO and high school clubs provided for me. One aspect of the RE-RASSOR project that I find

particularly rewarding is its potential to serve as both an engineering platform and an educational tool that

can encourage younger students to explore STEM fields.

One of the aspects of this project that interests me most is the opportunity to build upon an

existing engineering platform rather than starting from scratch. The RE-RASSOR project has been

developed by multiple teams over several years, which creates unique challenges involving system

integration, documentation, and long-term maintainability. This is especially so given the number of

repositories both private and public, and the number of different universities associated with this rover. I

find these challenges particularly interesting because they reflect many of the problems encountered in

real-world engineering projects.

From a technical perspective, I am interested in learning CAD and 3D printing to add to my skill

repertoire. While I have previous robotics experience, much of it focused on programming and traditional

robotics construction methods, making this project an excellent opportunity to broaden my skill set.

Furthermore, I am interested in improving project documentation and knowledge transfer throughout the

development process. During our first sponsor meeting, I noticed documentation was mentioned as a

weakness of earlier teams, and I believe this is a problem that can be improved through diligent work and

planning. Effective documentation is crucial for any long-term project, and I look forward to helping

improve this area.

Overall, I see this project as an opportunity to apply my background in robotics, software

development and computer science while gaining experience in new technical areas and contributing to a

system that can continue to be improved by future student teams.

### Nam Dang

I am excited to be a part of the RE-RASSOR development team because it combines several areas

that I have always been passionate about: space, robotics, and programming. I have always been

fascinated by the beauty and mystery of space and the incredible engineering that allows humans to

explore beyond Earth. The creativity involved in designing robotic systems checked out all that I am

interested in.

Since I was young, I have always been curious about how things work. I often took apart

household devices and toys simply to understand their mechanisms and learn how they all work together.

That curiosity and interest then turn into an interest in programming and engineering, where I can now not

only understand how systems work, but also contribute to creating and controlling them myself. The idea

of developing a rover capable of navigating terrain and manipulating objects through a robotic arm is

exciting because it combines software, electronics, and mechanical design into a single project.

Another thing that drew me to this project is that RE-RASSOR offers complete freedom in the

design process. Although earlier senior design teams have already developed a working rover, I still have

the option to either build upon that work by integrating a robotic arm or redesigning the system entirely,

and the arm can be whatever I want; it just needs to work. Which encourages creativity, sparks discussion,

and is simply more fun than following a predetermined design. And although I have not yet had the

opportunity to use a 3D printer myself, I have always wanted to design and make something of my own.

While I have previously built simple robots using motors and mechanical components, my

experience has primarily been on the hardware side, with only some limited opportunities to work with

the programming and control aspects of robotics. This project presents an ideal opportunity for me to

expand my knowledge in those areas and gain experience developing a complete robotic system as well as

creating meaningful connections with people and peers who share the same interests.

Coming from a developing country, I did not have the same level of exposure to robotics, and

programming opportunities as some of my peers. However, this has only made me more eager to learn

and take advantage of this opportunity. I am genuinely excited for the chance to contribute to RE-

RASSOR and learn from my teammates.

### Toluwalope Elugbaju

I ranked RE-RASSOR highly because it was one of the few projects that involved robotics and

gave us the opportunity to work on a physical system. Most of my coursework has been focused on

software, so I wanted to be part of a project where I could apply those skills while also learning about

mechanical design and system integration.

Another reason I was interested in RE-RASSOR was the open design process. The robotic arm

does not already have one fixed solution that we are expected to copy. Our team has to make design

decisions based on what the rover can realistically support and what the arm is expected to do. It forces us

to think through the reasoning behind each decision instead of only completing a set of assigned steps.

I am also motivated by the responsibility that comes with building on an existing rover platform.

Since RE-RASSOR has been passed between multiple teams, our design choices have to make sense

beyond the first working prototype. The arm has to be understandable enough for future teams to modify

or expand without starting over. That makes the project more meaningful to me because the final result is

not only the arm, but also the process and documentation that allow the project to continue.

Another part of the project that interests me is its connection to education. RE-RASSOR is meant

to be an accessible robotics platform that can help students learn about robotics and engineering design.

That gives the project a purpose that isn’t just building a prototype. If the arm is designed and

documented well, future students could use it as a starting point for learning or for developing new

features. Because of that, proper documentation and maintainability will be an important part of the

project.

I am also interested in the possibility of future expansion. One idea our team has already

discussed is using interchangeable end effectors so the rover could perform different tasks with the same

general arm structure. Even if that becomes a stretch goal, it’s still useful to think about how the design

could be expanded later. Designing with future work in mind makes the project more meaningful because

the team is contributing to a platform that other groups will continue building on.

Overall, I am motivated by the opportunity to help develop a functional robotic arm and see the

design progress from early discussion into a working prototype. I am expecting the project to be

challenging because the arm has to work as part of the overall rover. It needs to perform its task while still

being practical for future teams to understand, repair, and build on top of. Since RE-RASSOR is also

meant to be used in educational settings, it’s important to make the final design clear enough for students

to learn from it as well. That is what makes the project interesting to me. The work must result in a

functioning system but also must support the goal of making robotics more accessible to students.

### Max Grabov

RE-RASSOR is a project that touches a lot of areas I am currently interested in, namely robotics,

and systems programming. As someone who has been doing systems programming in the past year, I am

excited to have the opportunity to work on a final project that reflects my interests.

My experience with robotics goes back to middle school, when I joined my school’s robotics team for the

First Tech Challenge (FTC), and then later First Robotics Competition (FRC) in high school. Even after

graduating, I remained involved by returning as a mentor, helping students develop programming skills

and problem-solving abilities.

Through both my experience as a student and a mentor, I’ve had the opportunity to work both

with software and hardware on projects that share many similarities with RE-RASSOR, which is why I

believe that I have the experience necessary to succeed on this team. While I haven’t directly worked on

the same tech stack as RE-RASSOR, I'm confident that I can learn new tools quickly and adapt to an

unfamiliar technical environment. I view working on RE-RASSOR as an opportunity to contribute to a

project that interests me, and deepen my expertise in a field that I’m invested in.

To go in depth about the technical outcomes, I am excited to practice and learn more about CAD,

electronics, and other hardware. Most of my robotics experience has been on the software side, and while

I have experience working with other microcontrollers and electronics, it is not near my experience in

software. I believe working on RE-RASSOR will deepen my skills in these areas, as the project requires all components of robotics to be successful. Additionally, RE-RASSOR is building on top of an existing

teams’ work and decisions. While personal projects provide the opportunity to build systems from the

ground up, learning how to maintain and improve an established codebase is an essential skill any

software engineer must learn, and is something I am eager to gain more experience in.

Another reason I am interested in working on RE-RASSOR is the community impact. As

someone who has been mentoring robotics for the past 2 years, RE-RASSOR's goals of being student

friendly and deepening STEM involvement in young audiences resonate with me. One thing I would like

to propose in the future is bringing the RE-RASSOR rover over to my school and starting a program

there. I believe that it will be a big success over there due to the existing STEM support offered by the

school. Having the opportunity to not only develop the project but also introduce it into other

communities is an exciting prospect I would love to explore.

### Lucas Marrou

I ranked the RE-RASSOR project highly because it involves topics I am interested in.

Specifically, I'm interested in space exploration, robotics, and to a lesser extent 3D printing, all of which

are part of this project. I also believe my skills are a good fit for this project, so I will have an overall

smoother experience here than on a less fitting project.

I’ve long liked space exploration, in part due to how beautiful and interesting many of the

phenomena out there are, both to look at and to learn about. For example, many nebulae have amazing

shapes and colors, though some require specific imaging techniques to be seen with the human eye. There

are also neutron stars, which while we cannot directly look at them, have interesting structures on a

microscopic scale (“nuclear lasagna”).

I’ve also always liked robotics. I’ve been interested in programming for most of my life, having

started learning programming when I was only six years old, and robots are the most visible way to see

programming having direct results in the physical world. In addition, I am interested in robotics due to

how fun it can be to imagine and brainstorm ideas for robots, rovers, or similar machines, regardless of

whether those designs will ever be physically realizable.

3D printing is somewhat interesting to me due to its unique applications as a way to quickly and

automatically create arbitrary shapes. It is especially useful as a complement to robotics and exploration,

as it can be used to make a variety of specialized machines quickly, without needing molds for each,

requiring the designs to use the same set of parts, or requiring additional parts to be sourced manually.

My skillset matches the listed recommendations for this project well, as follows:

- Programming Experience: I started programming when I was only six years old and have

been interested in programming ever since. I have experience with C, C++, Python, Java,

Assembly, as well as various esoteric or uncommon programming languages.

- CAD Experience: I have been certified in Autodesk Inventor, a relative of the common CAD

program AutoCAD, but more specialized for complex 3D engineering tasks. I also have some

experience with TinkerCAD, having used it as part of a 3D printing seminar recently.

- Interest/Experience in robotics systems: I have previously been part of a team for the FIRST

Robotics Competition, back in 2020. However, I was unable to ever show off my work, as the

competition was cancelled due to the Covid-19 pandemic AFTER my team had already

arrived to compete.

I was also specifically interested in this project due to the association with NASA’s Kennedy Space

Center. I’ve visited the Kennedy Space Center before, and I am interested in potentially working there

one day. My hope is that by being part of this project, I may have an opportunity to prove my skills to

them and improve my chances of being accepted to work there.

## Project History & Previous Teams’ Productions

The work this team produced would be nearly impossible without the efforts of our predecessor teams.

The section below summarizes their efforts and how they impacted our design and its early considerations

during the design phase.

### 2022: The Previous Arm Attempt

Project Accomplishments:

The 2022 RE-RASSOR team was the first team tasked with creating a robotic arm to manipulate

3D printed pavers for the EZ-RASSOR rover. Like our own team, they were tasked with creating a low

cost, almost entirely 3D printed arm to be mounted onto the rover to complete various tasks. This team

focused on the software side and developed a complete software architecture around the robotic arm.

They implemented a ROS-based control framework, with an in-depth simulation, and investigated

computer vision techniques using NVIDIA Jetson Nano and cameras. Similar to ours, they also created an

application to control the arm through the Raspberry Pi & Arduino. While this project has a larger scope than ours and was ambitious and successful in what they were trying to achieve in the software side, their

physical design had significant mechanical challenges that caused the arm to be unable to integrate into

the RE-RASSOR platform.

One of the primary limitations that the 2022 team had was the significant emphasis on the

software portion of the project, rather than the mechanical design and robustness needed to manufacture a

mechanical arm. While their simulation showed good results, the translation to a real design proved to be

much more difficult.

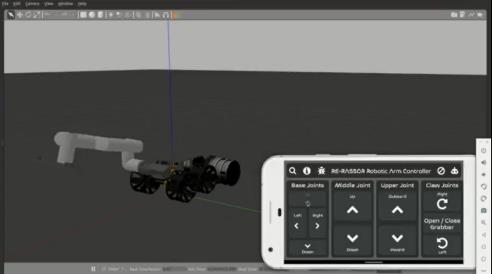
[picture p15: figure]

Figure 1: [1] 2022 Preliminary Simulation

Limitations:

The biggest issue this team faced, and one that heavily influences our current design, is the

weight of their proposed arm. The arm relied on several stepper motors distributed across the joints of the

arm to control it. As mentioned in the section about the 2025 RE-RASSOR team, stepper motors are very

powerful but much heavier than the BLDC motor design. As the arm extended outward, each joint was

forced to support not only its payload but also the weight of every motor and structural component farther

along the chain. Since the motors were so heavy, there were significantly higher torque requirements at

the base joints of the arm, which reduced the actual lifting capability. This is something the team ends up

identifying in their final design document.

The team also experienced difficulties transitioning from software simulations to hardware

implementations. The team mentions that while they were successful in simulating the arm’s motion,

integrating the hardware, electronics, and controllers introduced further challenges that didn’t have

enough time for a thorough implementation. They recognize that if they had validated their hardware

design early on before focusing on the simulations and complex software, this may have prevented many

of these integration problems for them.

Lessons Applied to our Design:

The work done by the 2022 RE-RASSOR team provided us with valuable lessons that directly

influenced some of our design decisions for our arm. One of those decisions was to keep our arm as light

as possible using the BLDC motors from the 2025 team. Since the weight of the arm required not only the

base but the joints as well to produce high torque, we wanted to avoid this scenario if possible. Learning

from the 2022 design, we plan to use a stepper motor for the base of the arm connecting to the chassis and

using BLDC motors for the joints of the arm. This way, we can still use the power of the stepper motor at

the base to rotate the whole weight of the arm, and it keeps the weight on the low side.

Another design decision that we are going with is to keep the 3D print infill percentage on the

low side. When looking at the arm design from 2022, one thing that stood out to us was the infill on the

arm pieces, as they were very high percentages and some cases 100%. This indicated to us that we want

to avoid using such a high infill for arm pieces and keep heavier pieces for the base of the arm. In a

similar way to using the BLDC motors instead of stepper motors for the joints, this allows us to keep the

base strong but the arm itself light.

Finally, their team showed us the importance of focusing on the hardware of the project, instead

of diving headfirst into the software of our mechanical arm. While their software was extremely

impressive, especially their simulations for their whole entire bot, it led to a lot of time being spent on the

software, when some of it could’ve been spent on validating the hardware design. Learning from their

experience, our team decided to dedicate two members of our team to working on our hardware design,

with our PM assisting us until we are confident in the arm design and it has been tested. This way, we can

have software and hardware design happening at the same time and produce prototypes as soon as

possible to allow software development to begin.

In summary, while the original RE-RASSOR arm did not fully achieve its intended goal, it

established an invaluable technical foundation for our team. By analyzing both its successes and its

limitations, our team has been able to develop a more practical mechanical design centered on lightweight

construction, brushless DC motors, and ensuring that we spend a significant amount of time vetting our

design.

### 2023: FSI’s Current V1 Rover

Project Accomplishments:

The 2023 RE-RASSOR Extension team focused on expanding the software of the existing RE-

RASSOR arm, rather than redesigning the mechanical structure. From their GitHub repository, they

primarily focused on integrating modern ROS2 into the RE-RASSOR software infrastructure, and

designing the remote-control interface, a mobile app, used to control the rover.

The largest accomplishment in software development they did for the RE-RASSOR is to refactor

using ROS2 Humble. This modernized and improved the earlier software architecture for the rover itself.

In addition, they also created updated ROS packages, scripts to launch the rover software and systemctl

services for the rover. These improvements created a more maintainable software platform for future

development.

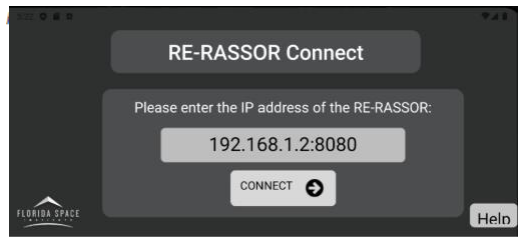
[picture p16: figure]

The next accomplishment was the

creation of a React Native application to

control the RE-RASSOR rover. Previously,

the team at FSI had to use a mobile app,

which had issues due to apple requiring

constant updates to stay on the app store. This

currently controls the rover and has the

opportunity to swap into different control

modes, which is perfect for our project. Their modular design allows us to easily add new commands to

the web application without significant architectural changes to the whole application.

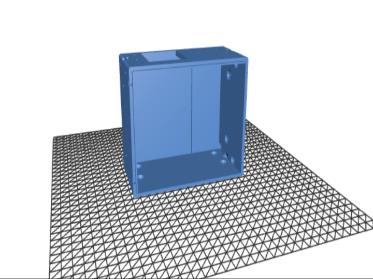
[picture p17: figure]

Figure 3: [2],[4] Current RE-RASSOR Body in CAD Software

Mechanically, the team worked to bring the RE-RASSOR rover into its current state. This

includes all the current CAD models on the RE-RASSOR rover, as well as updating the old EZ-RASSOR

Figure 2: [5] 2023 Team's Rover Connection UI rover with a new shoulder design. Because this team mostly worked to improve the software on the rover,

most of the borrowed and referenced work will pertain to their software.

Effects for our Project:

This team’s work directly influences most of the software development we have to do for the arm

design. Since this team set up the entire HTTP request system through the localhost application, our team

is deciding to build that by adding an arm module for our robotic arm. This will be an additional page

reusing and repurposing existing code for the base of the rover. Similarly, the ROS2 communication

framework can be extended to support our new BLDC motor controllers we plan to use from the 2025

RE-RASSOR team. While the underlying hardware differs between the two, using the 2023 team’s work

with ROS2 and the rest of the software on the rover, we will just need to add new modules dedicated for

arm control.

In relation to our stretch goals, the extension team also implemented the groundwork for a camera

subsystem on the RE-RASSOR rover. What they wrote enables camera streaming from the rover that can

detect ArUco markers in the lab. This is great for our design, as we can use their camera module to add

functionality to move the arm to a certain offset from these markers and/or other movements. From their

work, we don’t need to focus on writing a camera system from the ground up and instead can

immediately start leveraging a native library for RE-RASSOR.

### 2025: The Brushless DC (BLDC) Motor

Project Accomplishments:

The 2025 RE-RASSOR BLDC motor team successfully redesigned the drivetrain system of the

Florida Space Institute’s RE-RASSOR rover by replacing the previous stepper motor design with a well-

suited brushless DC motor system. The primary objective of this was to decrease the rover’s weight and

improve energy efficiency while maintaining the original rover’s architecture. This caused the new design

to focus on constant rotational control rather than power as with a stepper motor. Since our project relies

on us using their BLDC motor design for our arm, this assists us greatly with the nature of building a

mechanical arm requiring precision over power.

Beyond a prototype, the 2025 RE-RASSOR team produced extension documentation including

CAD files for all components, large documentation regarding process, materials, and project history,

allowing us to adapt their work to our own seamlessly.

Mechanical Design & Process:

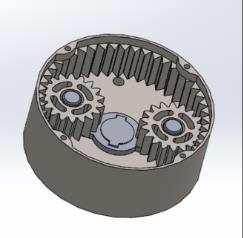
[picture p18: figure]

While the primary focus for the 2025 RE-RASSOR team was creating a

new motor for the rover to use, and controlling it, the team also

accomplished significant mechanical integration with the current RE-

RASSOR design. Instead of redesigning the whole entire rover to fit their

needs, they took a modular approach and designed the BLDC motors to be

compatible with the current chassis and other 3D printed parts. This is due

to the project being intended for additive manufacturing, allowing students

or researchers to make additions to the rover without friction.

Their design process involved evaluating motor mounting methods, configuration of their

gearbox, and alignment of the shaft of the motor with the rest of the mechanical components. The team

compared a direct-drive and geared-drive solution for their gearbox before recommending planetary

gearboxes or multi-stage spur gear reductions where additional torque was required. This means that their

design can be adapted to scenarios where more torque is required, or resources are scarce, and the cost

must be cheap, allowing students and teams like ours to adapt their design to our needs.

Another important contribution was maintaining compatibility with the rover's existing 3D

printed chassis. Rather than redesigning the entire vehicle, the team modified only the parts necessary to

accommodate the lighter BLDC motors. This reduced manufacturing costs and ensured that previously

printed rover components could still be reused. In addition, the team worked to ensure that materials

needed for constructing the gearboxes and motors themselves used readily available materials at the FSI

lab and already being used in other places of the rover. This makes it much easier and cheaper to

manufacture the rover, and any additional addons we need.

Software Design & Development:

The software developed focused on supporting the mechanical design goal of implementing the

BLDC motor design, which is allowing for efficient rotational control of the motors, while maintaining

Figure 4: [1][5] CAD RE-RASSOR Gearbox compatibility with the rest of the RE-RASSOR rover’s architecture. To accomplish this, the team

continued the use of the Arduino environment’s C++ library to get low level access to the hardware.

The software is designed to interface with the main controller for the rover, which then passes

commands to the Arduino Mega, which processes and generates PWM signals to control the motor. A

major design goal was maintaining constant motor speed despite changing mechanical loads. To

accomplish this, the software supports sensor feedback from Hall sensors or rotary encoders, allowing the

controller to continuously monitor motor position and speed. This feedback enables more stable motor

performance under varying operating conditions.

Due to the communication protocol mirroring the original stepper motor interface, the high-level

rotor software did not require major refactoring to accommodate the new drive system, which reduces the

effort to integrate the BLDC motors, and will allow for future projects utilizing their work to require few

code changes.

Effects for our Project:

Due to the nature of our group’s work, the effort made by the 2025 team will greatly influence

our hardware and software development and design. Since the goal of our project is to design a robotic

arm that must use this team’s BLDC motor design, their work directly ties into what we need to do. From

the creation of their design, it drives us to utilize their motors in our design due to their lightweight

design, and strong control of the motor’s rotation. Since a mechanical arm must be lightweight and stable,

the BLDC motor created by the 2025 RE-RASSOR team gives us an immediate solution to two core

challenges we would have to face. Without their design, we would either use the previous stepper motor

design and integrate it into our arm, leading to heavy weight and too much power, or create an entirely

new motor and gearbox design, significantly increasing the scope of our project. Therefore, we can focus

on the actual architecture of the arm and use their gearboxes and BLDC motors when needed. As shown

later in the document, there are a few key places that they will be placed to control the joints on the arm,

and since they are already integrated with the rest of the rover, it is easy to build an arm that utilizes both

the BLDC motors and a stepper motor for the base.

Their discussion and research into gearbox selection is valuable to us because robotic arms

require high joint torque with precise control. Although our application emphasizes positional accuracy

rather than continuous vehicle motion, the tradeoffs between direct drive, planetary gearboxes, and spur gear reductions remain nearly identical to the 2025 team’s study. Their analysis provides useful guidance

when determining the appropriate transmission for each arm joint.

In terms of their software driving our design, our team will be interfacing with their code to

control the BLDC motors over HTTP requests like the drive controls on the rover. Since their software is

modular and easy to use, will have their packages as a dependency and modify the rover Arduino code to

communicate with our arm subsystem. This allows us to focus on a high-level software design, without

needing to delve into the low-level details involved in programming the motors from scratch.

Overall, they establish a strong baseline for our design for which our team can start our robotic arm,

without worrying about hardware implementation. This way, we can focus entirely on the mechanical

design and communication between the localhost server and the rover.

# Project Characterization

## Our Commitment to Documentation

Documentation is especially important for RE-RASSOR due to the way the project is passed

between student teams. Our arm design cannot end as a prototype that only our group understands. Future

teams should be able to open the project files, understand the current design, and continue development

without reverse engineering from scratch. The documentation should make the final design

understandable as a system.

The mechanical documentation should clearly describe the final arm assembly. This should

include the CAD files, part versions, print material, print settings, and assembly steps. If a part has a

specific orientation, support requirement, or tolerance issue, that should be written down near the part it

applies to. Future teams should be able to tell which files current and which ones are only used for testing.

File names should also be organized clearly, so the final design is not mixed with outdated prototypes.

Any part that changed during testing should be documented with a short explanation of what

changed and why the previous version was rejected. If a joint, mount, or gripper part fails during testing,

that failure should be recorded and explained instead of being removed from the project's history. Failed

designs can still prevent future teams from repeating the same mistake. For example, if a joint was too

loose, a mount flexed too much, or a gripper could not hold the paver consistently; those results should be

included with the design notes.

Assembly documentation should be detailed enough for someone outside our group to rebuild the

arm. The instructions should show how the printed parts connect, where each motor is mounted, how the

gripper is installed, and how the arm attaches to the rover. Photos or diagrams should be included when

written instructions are not enough. If a step requires careful alignment or a specific order of assembly,

that should be stated clearly. This would reduce confusion for future teams and make repairs easier if the

arm needs to be taken apart.

The software documentation should explain how the arm controls connect to the existing rover

system. Each command should have a clear purpose and should match the physical movement it creates.

Future teams should be able to identify which command controls the base, shoulder, elbow, wrist, or

gripper without searching through the full codebase. Any setup steps, dependencies, or configuration

details should also be written clearly, so the software can be run again after the project is handed off.

The control documentation should also connect the user interface to the physical arm. If a button,

keyboard input, or HTTP request moves a joint, that relationship should be recorded. This will make

debugging easier when a command does not produce the expected movement. It also helps future teams

modify the interface without accidentally changing the wrong control behavior. If any commands are

limited for safety or only meant for testing, those limits should be stated.

Testing documentation should connect design decisions to actual results. Each major test should

record the setup, the part version used, the observed behavior, and the design change that followed. This

applies to mechanical testing, software testing, user interface testing, and full rover integration testing. A

short record of what worked and what failed will be more useful to future students than only showing the

final successful demonstration.

The final handoff should also include known limitations. If the arm works only within a certain

range, that range should be stated. If the gripper struggles with certain paver positions, that should be

recorded. If the mount, wiring path, software controls, or counterweight concept still needs improvement,

those issues should be left as clear notes for future work. Limitations should be written directly so future

teams can plan around them instead of discovering them during testing.

The final folder should separate CAD files, software files, testing notes, assembly instructions,

and reference material. A main README should explain where each part of the project is located and

what files are needed to rebuild or run the system. This makes the project easier to build on and gives

future teams a stronger starting point.

## Our Tech Stack

A variety of physical materials, software, and other technological products are or will be used in the

rover, the associated peripherals for the rover, and/or the development process as broken down below

### Project Specific Materials

Printing Materials [1][5]

- Polylactic Acid (PLA)
- Used for rapid prototyping and early design iterations.
- Polyethylene Terephthalate Glycol (PETG)
- Used for manufacturing final robotic arm components intended for permanent

installation on the rover.

- Bambu Lab X1 Carbon with Automatic Material System (AMS)
- The primary 3D printer used to manufacture the robotic arm and its associate

prototype components.

Mechanical Components [1][5]

Rover Electronic Components

- Brushless DC (BLDC) Motors
- Actuate the rover wheels, robotic arm joints, and end effector through custom 3D-printed

cycloidal gearboxes.

- Raspberry Pi 4 and/or Libre Computer (Le Potato)
- Execute the rover control software and facilitate HTTP communication between the user

interface and onboard systems.

- Arduino Mega 2560
- Controls individual BLDC motors and interfaces with low-level hardware.
- Emergency Stop Switch
- Model: CMORSUN BE102 Push Button

- Provides an immediate method of disconnecting power during testing or emergency

situations.

- Battery Pack
- Model: Nermak LiFePO₄ 12.8V Battery
- Supplies electrical power to the rover and robotic arm.
- 12V Brushless Cooling Fan
- Maintains airflow through the rover enclosure to cool onboard electronics.
- Camera System
- Primary Model: ArduCam UC-A53
- Provides live video feedback for teleoperation.
- Router
- Model: NetGear Nighthawk
- Creates an isolated wireless network for rover communications, avoiding restrictions

imposed by institutional networks.

- Engineering Workstations
- Used for CAD modeling, embedded software development, and user interface

programming.

Software Components

Version Control

- Git & GitHub
- Version control, collaboration, and source code management.
- Google Drive
- A backup artifact for project handoff and presentation purposes
- Onshape

- A webapp CAD platform used by FSI for the purposes of sharing and managing finalized

component and mechanism designs

RE-RASSOR Software [1][5]

- Arduino Firmware
- Microprocessor Software
- Network communication services.

RE-RASSOR User Interface [1][5]

- React Native
- Expo
- HTTP Connection Service

Development Environments [1][5]

- Arduino IDE
- Android Studio
- Visual Studio Code

Simulation

- Gazebo
- Simulates rover operation prior to physical deployment.

Computer-Aided Design (CAD) Software

- AutoCAD
- Fusion 360
- Used throughout the mechanical design process.

Manufacturing Software [1][5]

- Bambu Studio
- Generates G-code for the Bambu Lab X1 Carbon.

Communications and File Sharing

Discord

- Used for daily communication and project coordination.
- GitHub webhooks automatically post commits, pull requests, and repository activity to the team's

Discord server, improving visibility into ongoing development.

Email

- Used for communication with the project sponsor and faculty.

Microsoft Office

- Used to prepare project documentation and deliverables.

Jira

- Used for project management through a Kanban workflow.

Testing and Development Locations

Florida Space Institute Laboratory

- Used for manufacturing, assembly, and robotic arm development.

Exolith Laboratory

- Used to evaluate rover and robotic arm performance in a simulated lunar regolith environment.

# Concept of Operations

The primary operational objective of the 2026 iteration is the integration of a lightweight, multi axis

articulating manipulator capable of acquiring, transporting, and precisely positioning standardized 3D-

printed interlocking pavers without compromising the rover's chassis stability or mobility.

# Operational Context & Mission Profile

1In terrestrial and planetary exploration scenarios, surface mobility platforms must possess manipulation

capabilities to accomplish infrastructure construction, sample collection, hazard mitigation, and

instrument placement. The RE-RASSOR platform simulates lunar and Martian regolith excavation and

construction workflows on a modular scale. Previous versions developed autonomous surface mobility

mechanisms for the drum. The manipulator to be added in 2026 turns the rover into an active surface

construction platform.

The mission profile is based on standardized paver handling. The rover must traverse simulated

regolith terrain (e.g., UCF Exolith Laboratory), recognize standardized 3D-printed pavers weighing less

than 1.0 lb (approx. 450 grams), approach the target within the arm’s reach envelope, actuate the 4-DOF

manipulator to grasp the paver, lift the payload while actively managing the vehicle’s balance, traverse

across the operational field, and place the paver into a designated construction grid or storage receptacle.

# System Operational Scenarios & Lifecycle Phases

For safe, reproducible, and deterministic execution in field operations and educational

demonstration, the operational workflow is divided into six distinct sequential phases. Each phase has

explicit entry criteria, active execution monitoring, and exit condition checks.

Phase | Phase Name | Primary Objective | Key Operational
| | | Actions
Phase 0 | Pre-Flight & | Verify power, network | Boot Raspberry Pi
| Initialization | link, & hardware health. | server, establish local

Wi-Fi, run homing

sequence on stepper

base & BLDC joints,

verify emergency stop

loop.

Phase 1 | Target Search & | Navigate rover into | Operator drives rover
| Approach | payload reach envelope. | using teleoperation UI

and ArduCam feed;

aligns chassis within

15–25 cm reach vector

of target paver.

Phase 2 | Payload Acquisition | Grasp target paver | Deploy arm from
| | securely with gripper. | stowed position,

compute

joint/workspace target

coordinates, actuate end

effector gripper, verify

contact load.

Phase 3 | Transport & Stability | Traverse field while | Retract arm into low
| | maintaining stability. | movement carry

configuration; adjust

rear counterweight if

necessary; drive rover

to destination site.

Phase 4 | Precision Placement | Deposit paver on target | Extend arm to
| | construction grid. | placement coordinate;

actuate end effector

release; execute brief

clearance lift to avoid

disturbing placed paver.

Phase 5 | Stow & Power Down | Return arm to safe rest | Return manipulator to
| | position and power off. | stowed resting

geometry on chassis

plate; log operational

metrics; issue server

shutdown command.

# User Operational Interactions

The concept of operations accounts for three distinct user roles interacting with the RE-RASSOR

platform, each possessing specific operational requirements, interface privileges, and safety

responsibilities:

Rover Field Operator:

This uses the React Native web/mobile control interface to teleoperate with the vehicle and

robotic arm in real time. The operator relies on visual feedback from real-time telemetry gauges (joint

angles, motor power states, battery voltage) and or from the ArduCam camera feed (additional goals). The

operator maintains continuous situational awareness and is authorized to trigger manual emergency stop

overrides.

Research & Academic Lead:

Configures automated test routines, conducts manipulation repeatability evaluations, and collects

physical performance metrics (e.g., motor current draw under load, thermal dissipation, mechanical joint

deflection). Interacts with high-level Python REST API endpoints and ROS2 telemetry topics to execute

script-driven experiment suites.

System Maintainer / Future SD Team:

Modifies firmware logic, re-calibrates motor encoders, updates CAD structural components, and

maintains codebase dependencies. Relies on comprehensive hardware wiring schematics, modular

software documentation, and explicit mapping rules.

# Environmental, Physical, & Electrical Constraints

Successful operation of the RE-RASSOR arm requires strict adherence to physical, thermal, electrical,

and network boundary conditions:

Mass & Center of Gravity Envelope:

The primary chassis body is an additive manufactured using lightweight PETG. Uncompensated

extension of the multi axis manipulator drastically shifts the system's Center of Gravity forward. To

prevent tipping or loss of front-wheel traction, the arm structure must remain under 1.2 kg in total mass,

with an operational payload limit of 1.0 lb. (450g) at a maximum forward reach of 30 cm.

Thermal Operating Limits:

BLDC cycloidal gearboxes and NEMA 17 stepper motors generate heat during sustained holding

or lifting operations. PETG deforms at temperatures exceeding 80°C (176°F). Thermal management protocols dictate continuous cooling airflow via onboard 12V fans and automated software power

throttling if motor temp estimates exceed 65°C.

Dedicated Wireless Network Topology:

Institutional campus networks impose strict port security, blocking local peer-to-peer REST

requests and SocketIO streams. Operations dictate using an isolated NetGear Nighthawk wireless router

operating on standard 2.4GHz/5GHz bands with fixed IP assignments (e.g., 192.168.1.100 for the

onboard microprocessor).

Power Delivery Architecture:

Electrical power is supplied with a 12.8V LiFePO4 battery pack equipped with an inline

CMORSUN BE102 physical Emergency Stop switch. Step-down buck converters supply stable 5V power

to the Raspberry Pi / Le Potato board and Arduino Mega 2560, while raw 12.8V bus power feeds the

motor drivers.

# End-to-End Operational Workflow Architecture

The complete operational data and physical actuation flow across the RE-RASSOR ecosystem follows a

strict distributed pipeline:

1. Input Capture: The operator interacts with React Native UI controls (sliders, joysticks, or

preset buttons) on a remote tablet or workstation.

2. REST Network Dispatch: The client app dispatches an asynchronous HTTP POST request

containing structured JSON payloads to port 5000 of the Flask server (`server.py`).

3. Verification & ROS2 Translation: `request.py` validates payload schema constraints. Valid commands

are instantiated as kinematic state objects in `command.py` and published to ROS2 topics

(`/ezrassor/arm_instructions`).

4. Low-Level Serial Encoding: The `serial_driver.py` node converts ROS2 instructions into

compact binary wire protocol opcodes and streams them across USB serial links (`/dev/arduino_arm`) at

115200 baud.

5. Microcontroller Execution: The Arduino Mega 2560 receives opcodes, generates PWM

signals, coordinates motor driver pulses, reads magnetic encoder feedback, and enforces hardware limit

switches.

6. Telemetry Feedback Loop: Sensor data and ArduCam video streams return asynchronously to

the Flask server via WebSockets (SocketIO) and are rendered on the operator dashboard at 30 FPS.

# Design Documentation

## Research & Investigation

Before any computer aided design began, our team performed a detailed investigation into existing

manipulator designs, structural considerations, and previous work done by the 2022 arm team. While the

primary objective was to design a robotic arm capable of manipulating the designated 3D printed pavers,

we had to make significant engineering decisions before settling a design. This became very apparent when

looking at the arm developed by the 2022 arm team. While their arm was strong enough to complete the

task, due to the complexity and weight of the arm being too much, it was unable to even be attached to the

RE-RASSOR rover. Weight, structural rigidity, manufacturability, software compatibility, power

consumption, and future maintainability all influenced the direction of the project.

In addition, since our team was working off an existing system, we had to consider how the arm

would integrate cleanly with the rest of the rover. This meant we did have some baselines we could

immediately work off, such as what electrical components we would need (BLDC Motors being a

requirement), and where the arm would be mounted. This, however, gave us some limitations, as we had

existing hardware that we had to be mindful of (such as the center battery and the rest of the motor

connectors). Throughout the investigation process, our team evaluated potential solutions against the

project's minimum viable product while considering stretch goals that future development teams could

pursue.

## Defining Requirements

The first stage of investigation involved identifying the functional requirements of the arm we

planned to build, before selecting any specific design. We decided to determine exactly what we expected

the arm to do before modeling components in 3D Modeling software such as Fusion 360. The robotic arm

needed to retrieve, transport, and accurately place standardized 3D-printed pavers while remaining

mounted to the existing RE-RASSOR rover. Unlike industrial robotic manipulators that operate from

rigidly mounted bases, the RE-RASSOR arm would function on a lightweight mobile platform whose

stability changes continuously as the arm moves. This immediately introduced design constraints that

heavily influenced every later engineering decision.

Due to these constraints, several requirements were immediately established for us:

- Sufficient arm reach to access 3D printed pavers in front of the RE-RASSOR rover.
- Adequate lifting capacity for the pavers.
- Low overall weight to minimize changes to the rover’s center of gravity.
- Being compatible with the concept of additive manufacturing.
- Modular construction to allow for stretch goals and future development.
- Compatibility with the existing software and electronics architecture.
- Ease of maintenance for damaged components.
- Low mechanical complexity to be in line with the RE-RASSOR target audience, being school

age children.

Through establishing these basic requirements as our baseline, designs could be evaluated against

an objective list rather than intuition or feeling.

## Degrees of Freedom

Selecting the appropriate number for our degrees of freedom was another critical and significant

research effort for us. While additional joints can improve the dexterity of the robotic arm, they easily can

multiply the mechanical complexity of the final product. In line with our weight and complexity

requirement, we immediately knew that we would not be doing a robotic arm with 6+ degrees of freedom.

While they do provide excellent dexterity and control, this would require more motors to pilot every joint,

more filament and parts to print, significant engineering skill which we may not be equipped to handle

due to our limited background knowledge and added weight. These considerations led us to believe we

had to keep the Degrees of Freedom limited, while still having enough complexity to accomplish our

basic requirements.

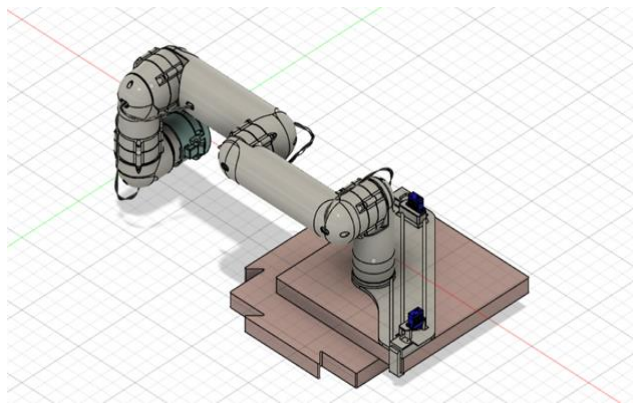
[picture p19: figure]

Figure 5: [1] Example 6+ DOF arm from the 2022 Team

On the same note, going for a simple 2 degree of freedom robotic arm would also not work in our

favor. We had a reach requirement that we had to achieve, and having such a simple system would mean

longer static parts which would worsen the weight requirements and be harder to control.

In the end, our team opted for a design consisting of a rotating base, shoulder joint, elbow joint,

and end effector, totaling 4 degrees of freedom, with one of them being strictly limited to on the RE-

RASSOR rover. This allowed us to have enough complexity to be able to manipulate our pavers in a

simple way, while also ensuring that we remain in weight and have a properly scoped complexity. A Base

degree of freedom helps us with this as well, since it is significantly easier to attach to the rover, and can

be a stronger motor to provide enough torque to carry the entire weight of the arm. This design also

permits us for out of scope stretch goals, for example, a wrist joint remains feasible as future work

without requiring fundamental changes to the arm architecture, as parts can be swapped as we need.

## Actuation

Motor selection proved to be one of the most influential decisions that we had to make in the

investigation process. Depending on the actuator we choose, it can completely change the degrees of

freedom, how we design certain components, weight limitations, and much more. In our project's case,

our sponsor highly recommended and encouraged the use of BLDC motors. These were created by the

2025 RE-RASSOR team and proved to be a great solution to our needs. Before immediately choosing

them, however, we had to weigh the pros and cons with what we could use.

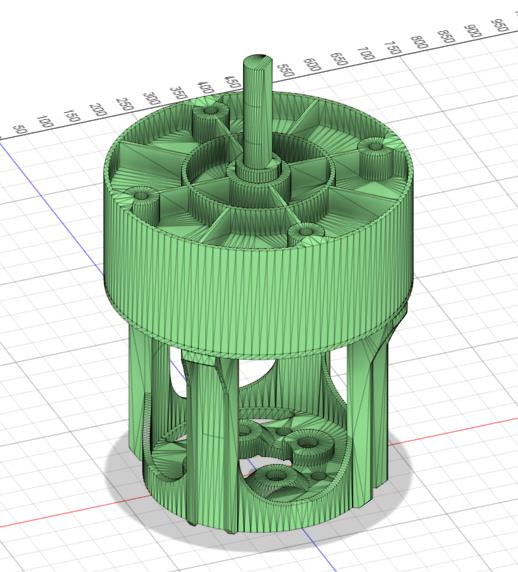
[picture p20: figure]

Figure 6: [5] Gearbox Reconstructed from the design made by the 2025 BLDC Motor Team

In our research, we came across two other options being stepper motors and servos. Traditional

hobby servos were initially a great idea, because of their integrated position control and ease of

implementation. However, commercially available servos capable of supporting the expected payload

would significantly increase project cost while limiting scalability. While they would be great for a

smaller scale robotic arm, they wouldn't work for our case. We also investigated stepper motors. We

initially had much skepticism as these were the motors that were used for all the actuators of the 2022

RE-RASSOR arm team. While stepper motors are very powerful, this led to them having significant

weight issues for other reasons. Since every motor mounted farther along the arm becomes additional

payload for preceding joints, a fully stepper-driven arm would require dramatically larger motors near the

shoulder and base. While we decided to not pursue using all stepper motors, they would be useful for our

base joint since we needed a large amount of torque to control the entire arm.

Finally, Brushless DC motors presented a compelling alternative. Earlier RE-RASSOR

development had already demonstrated a lightweight BLDC motor platform compatible with the rover's

existing software architecture. Although BLDC motors require more sophisticated control electronics,

they provide improved power density, lower weight, smoother operation, and greater efficiency than

comparably sized stepper motors. Additionally, since the 2025 team made an easy to manufacture 3D

printed solution for the gearbox, these were very easy to integrate with the rest of the RE-RASSOR rover.

Additionally, since the part files were available to us already, we can simply assemble these components

together to produce the gearbox produced in figure 6. Other options would require us to create or modify

other gearboxes ourselves. This ended up saving us a lot of time when dimensioning the components we

made, discussed later in the document.

Based on our research, our team decided to go with a hybrid approach. As mentioned earlier, we

would control the base joint connected to the rover chassis with a stepper motor to get the maximum

torque possible with little risk of weight issues. While for the rest of the arm, we would use BLDC motors

to control the remaining joints. This way we can minimize the arm's weight while having sufficient power

to control the mechanism.

One point that is up for debate is the end effector mechanism. Since the end effector is much

more delicate, in testing we may find that using a BLDC motor for the end effector may be either too

heavy, or too strong for it. In this case, we may opt to use a smaller servo or modify the existing BLDC

motor gearbox to fit better with the end effector design.

## Final Design Direction

Following our investigation and necessary requirements we derived, our team concluded that our

approach would be a lightweight serial manipulator arm design designed for additive manufacturing.

Similar to the 2022 team, which also opted for a serial design with chained stepper motors. The arm

would use modular construction techniques, and incorporate a stepper driven base with BLDC motors

driving the rest of the mechanism. Due to our limited engineering background, we also opted to look into

existing designs online as a way to jumpstart our progress, at the recommendation of our sponsor. Rather

than creating an entirely original mechanical layout, we elected to investigate existing open-source

robotic manipulators that embodied many of these characteristics. Among the available designs, the

EEZYbotARM provided the closest match to the project's objectives. Its modular construction, extensive

use of additive manufacturing, and publicly available CAD models provided an excellent mechanical

starting point that could be substantially modified to satisfy our requirements. While this did serve as a

great starting point and inspiration, ultimately many of the parts done now, and in the future, are

completely redesigned to fit our needs. This is due to the scaling of the EEZYbotARM, and different

hardware that was used for their mechanisms. Despite this, it still served as a great reference for a

working version of our final product. This investigation ultimately served as the foundation for the design

adaptations discussed in the following section.

## Our Inspiration During Initial Design

When researching mechanical arm designs, we took into consideration many factors that we

needed to satisfy, such as degrees of freedom, weight, and overall control of the arm. One completely

open-source design we found gives us a large foundation that we can work on to adapt to the RE-

RASSOR rover. That design comes from the EEZYbotARM design. This project provides a fully open-

source, desktop-scale robotic arm designed to be inexpensive, easy to manufacture, and almost entirely

fabricated with common 3D printing materials. Like our initial sketches and ideas, this arm is a 3 degree

of freedom arm (excluding the base), that utilizes modular and cheap components for their final product.

Since all the CAD models are publicly available, it is a popular design for robotics projects to adapt an

arm design to suit their needs.

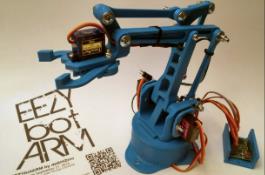
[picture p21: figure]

Figure 7: [26][27] EEZYbotARM Sample Arm

One of the best parts of the EEZYbotARM is its emphasis on additive manufacturing. Nearly

every structural component is designed to be 3D printed, including the base, shoulder, elbow, wrist

supports, motor mounts, and linkages. This dramatically reduces manufacturing costs while allowing

damaged parts to be quickly reprinted. The CAD models are organized into modular assemblies, making

it straightforward to modify individual joints without redesigning the entire arm. The printed components

are lightweight in their design as well. The arm also incorporates printed bearing supports and mounting

surfaces that simplify assembly using commonly available hardware that is available in most labs.

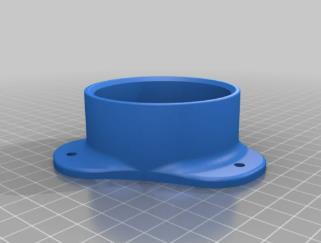
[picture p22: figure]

Figure 8: [26][27] EEZYbotARM Base

Effects on Our Design:

The EEZYbotARM serves as the mechanical foundation for our robotic arm but will require

several significant modifications to satisfy the requirements of the RE-RASSOR project. The first core

modification is completely overhauling the motor drive system to use the required BLDC Motors. This

will help us in the end, as we would end up needing more strength compared to the small servos powering

the arm design here due to the scaling. This will also require us to rewire and ensure that the

EEZYbotARM design can interface well with the electrical components required to move each of the

BLDC motors in our arm. In addition to using these motors to drive the arm, we are deciding to go with a

stepper motor to power the base of the arm. This is because the EEZYbotARM modifications we will

make will cause the arm to be much larger in scale, so we will need a strong base to generate enough

torque for the arm.

Another major modification we will need to make is the scaling and reworking of many of the

components in the arm design. Because this arm was developed as a standalone system, it is not meant to

interface with other pieces of hardware and/or a chassis like the RE-RASSOR rover. Not only will we

need to integrate a modified version of the arm into the front of our rover, but we will also need to scale

the arm's design. Our application requires a larger workspace and increased reach, so many of the

structural components will need to be resized.

A final effect on our design is the reinforcement of a claw/gripper design for the end effector. In

our original sketches and talks, we wanted to go with a claw that could pick up the 3D pavers as specified.

In seeing this design, it reinforced the idea that it is feasible and acted as proof of concept for other items.

In the EEZYbotARM, the gripper is designed horizontally to pick up small items such as a ball. A new

end effector will need to be developed to better accommodate the objects and tasks expected during

operation (such as our pavers) while maintaining compatibility with the wrist assembly.

Overall, while many significant design changes are needed, the EEZYbotARM project acts as a

great starting point for us as all the CAD files are publicly available, and we can see proof of concept of

what we need to build for the rover.

## Testing Procedures
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

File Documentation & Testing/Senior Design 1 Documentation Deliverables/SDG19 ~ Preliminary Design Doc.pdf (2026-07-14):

## 2026 RE-RASSOR Preliminary Design Document

Prior Designs & Iterations

2022 RE-RASSOR Original Arm Team

Project Accomplishments:

The 2022 RE-RASSOR team was the first team tasked with creating a robotic arm to manipulate

3D printed pavers for the EZ-RASSOR rover. Like our own team, they were tasked with creating a low

cost, almost entirely 3D printed arm to be mounted onto the rover to complete various tasks. This team

focused on the software side and developed a complete software architecture around the robotic arm.

They implemented a ROS-based control framework, with an in-depth simulation, and investigated

computer vision techniques using NVIDIA Jetson Nano and cameras. Similar to ours, they also created an

application to control the arm through the Raspberry Pi & Arduino. While this project has a larger scope

than ours and was ambitious and successful in what they were trying to achieve in the software side, their

physical design had significant mechanical challenges that caused the arm to be unable to integrate into

the RE-RASSOR platform.
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

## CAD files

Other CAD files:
Arm & Attachments/CAD Files/STL & Dev Files/V1 Hand Designs/V2Gripper/PrintFiles/MainFrameAndMotorHousing.gcode.3mf
Base Cart & Control/Rover V1/3D Printing/3D Model STLs/Main Components/MainBody.stl
Arm & Attachments/CAD Files/STL & Dev Files/V1 Hand Designs/V2Gripper/Individual Parts/MainFrame.stl
Base Cart & Control/BLDC CAD/Planetary Gearbox/CAD/Assem5.SLDASM
Arm & Attachments/CAD Files/G-code & Printing Files/Arm & Base Components/LowerMainArmPrint.gcode.3mf
Arm & Attachments/CAD Files/STL & Dev Files/Full Arm & Hand Assembly.dwg
Arm & Attachments/CAD Files/STL & Dev Files/LowerMainArm.stl
Arm & Attachments/CAD Files/STL & Dev Files/Base Assembly (Base + Connector + Stepper + gearbox.stl
Arm & Attachments/CAD Files/STL & Dev Files/BLDC Fusion Assembly.stl
Arm & Attachments/CAD Files/G-code & Printing Files/Arm & Base Components/GearboxBasePrint.gcode.3mf
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

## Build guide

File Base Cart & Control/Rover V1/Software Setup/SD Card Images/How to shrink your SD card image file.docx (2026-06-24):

# How to shrink your SD card image file

# When you create an image of an SD card, it includes all unused space, making the image as large as the card itself. For example, a 64GB SD card using only 5–6GB of data will still produce a 64GB image. This guide shows how to reduce it to just the used space.

# *** Note that this guide is for the Software Developers working on this project and not teachers. Please move onto another guide if you are not intentionally trying to reduce the size of the SD card.

Requirements

To do this, it is recommended that you have a computer running Linux, an SD card reader, the SD card you want to copy, an empty SD card to test your image, and a flash drive with enough space to hold the image.

1. Take your SD card that has everything on it and put it into the SD card reader. We will call this SD card the old card and the empty one the new card moving forward.
2. Plug that reader into your Linux computer. This is so that we can mount the SD card and make an image of the card.
3. Use the command below to identify which name your SD card is using:
  - lsblk
  - Note: If I was using a 32GB SD card, then as seen in the picture, sdb would be the name of my card.
4. Mount the SD card
5. Create an image of the SD card so we don’t destroy our old SD card
  - sudo dd if=/dev/sdX of=sd-card-full.img bs=4M status=progress
  - Note: Replace sdX with the name of the SD card or mount name.
  - Note: you can also choose a different name than sd-card-full but for this document we will be referring to the image as such.
6. Create a loop device of the image
  - sudo losetup --partscan --find --show sd-card-full.img
  - Note: A loop device in Linux is a special kind of pseudo-device that allows you to treat a regular file—such as a disk image (.img, .iso)—as if it were a physical block device (like a hard drive or USB stick).
  - Note: We will only edit the image so that our old SD card remains untouched.
7. Use the mount point from step 4 to see the usage of the file
  - sudo btrfs filesystem usage /mnt/btrfs
  - Note: I named my mount point /mnt/btrfs because I knew my SD card uses a Btrfs (B-tree file system), but you can name yours whatever you choose.
  - As seen below I only used 5.64GiB but had allocated 6.39GiB

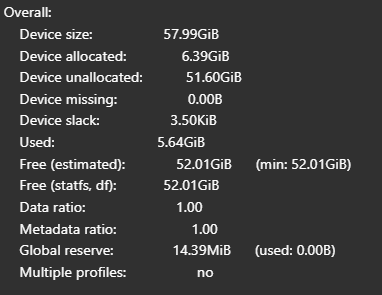
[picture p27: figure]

8. Resize the btrfs to above your allocated amount
  - sudo btrfs filesystem resize 8GiB /mnt/btrfs
  - Note: GiB will not stand for Gigabytes but Gigibytes, do not make this mistake.
  - Note: I chose to do 8GiB but 7 would also suffice, just note that the closer you get the more you run the risk of corruption
9. Unmount your mount point
10. Open parted
  - sudo parted /dev/loop0
  - Note: If you do not have it installed, then install it
11. Set unit to GiB and resize the btrfs
  - (parted) unit GiB
  - (parted) resizepart 2 8.00GiB
  - (parted) quit
12. Verify that /etc/fstab has been updated
  - Note: This is a system file on Linux that tells your system which partitions to mount and where to mount them at boot time
  - Mount the image again and see if the PARTUUID’s match
  - sudo blkid
    i. Note: A command to tell you the PARTUUID’s for each device
  - cd mnt/btrfs/etc
  - sudo nano fstab
    ii. Note: Compare to the PARTUUID’s given from blkid and if different update to the new values
    iii. Note: The value’s position does matter; one should be for boot and the other for root
13. Get the end sector of the image
  - sudo fdisk -l sd-card-full.img
  - Note: In the column that says End, take the value that is there and round it up to a comfortable value. Ex: 19660800 --> 20000000 (Remember the closer we are the more we risk corruption due to data cutoff)
14. Multiply the value from the last set by 512 because of byte sectors
  - 20000000 *512 =10,240,000,000
15. Truncate the image
  - truncate -s 10240000000 sd-card-full.img
16. Mount a Flash drive and cp the img file to the mount point and you will have your img
17. Test the img for corruption by flashing onto a new SD card and ensure the boot properly goes through.

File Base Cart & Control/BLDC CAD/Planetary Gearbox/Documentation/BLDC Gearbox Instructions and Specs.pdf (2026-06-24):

# FSI RE:RASSOR BLDC Gearbox Assembly Instructions and Datasheet

Specs:
Weight (no motor) | ~ 27 grams
Gear ratio | 3.769 : 1
Tooth count:(ring \ planet \ sun) | 49 / 18 / 13
Intended input RPM range: | 0 - 1000
Lubrication Type: | Silicone Grease (optional)
Intended Filament: | PETG

Additional Hardware list:
M2 screws 5mm (+\- 1) length | 4x (cap)
M2 screws 8mm length | 3x (sun gear)
M4 screws 4mm length | 8x (motor mount and encoder board)
M4 screws 8mm length | 8x (for cycloidal gear mounting)

Feature overview:
This gearbox was designed specifically for 3d printing. No additional parts are needed besides screws to assemble. All gear pairs tooth counts are co-prime, and the tooth pressure angle was increased to 30 degrees. These Features were chosen to increase wear life and efficiency. This gearbox is intended for use with the FSI RE:RASSOR BLDC motor system (SD2 Spring 2026).

Printing Notes:
It is recommended to print the “BY_OBJECT” plates. From my experience, they have much better tolerances and surface finish creating a much smoother operation.

This system was prototyped and printed on a Bambu Labs P1S. My printer has a pretty consistent +0.005in on the final part compared to the CAD models. This may vary from printer to printer. Since the bearing surfaces are 3d printed, in order to reduce play in the system, a very very slight interference fit is most desirable on the “output shaft bushing”, although not mandatory. The print includes a variety of drive shaft bushings with slightly over or under sized bushings (printed on plate 2), find the best fit for your gearbox on your printer by testing them. If in doubt use the default size (prints on plate 1).

Mounting hole configuration (in mm):

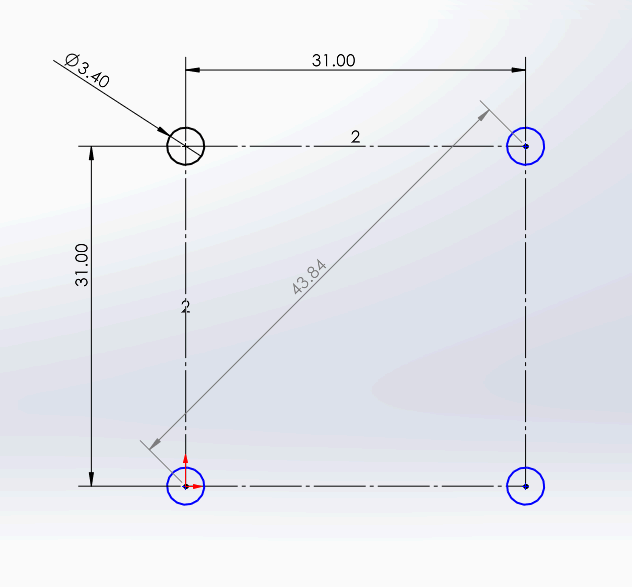
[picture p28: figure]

## Assembly Instructions

Step 1:
Print all of the parts in the gear box .3mf file. Test the fit of the “drive shaft bushing” with both the “Ring Gear” and “Planet Carrier” parts. It should be free spinning but with as little free play as possible.

There are multiple sizes of driveshaft bushing provided on plate 2

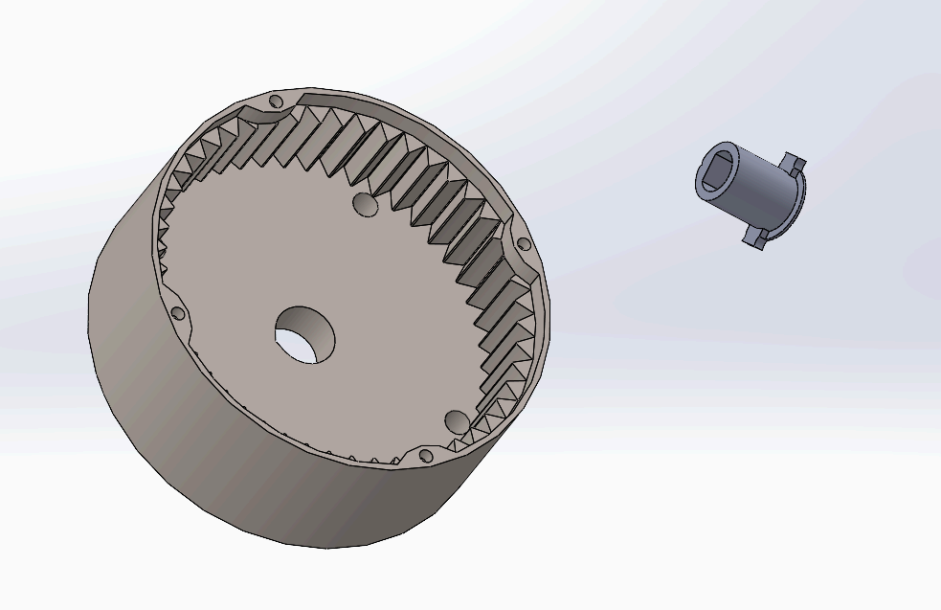
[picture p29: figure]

Step2:
Assemble the drive shaft and the drive shaft bushing. Secure with SuperGlue

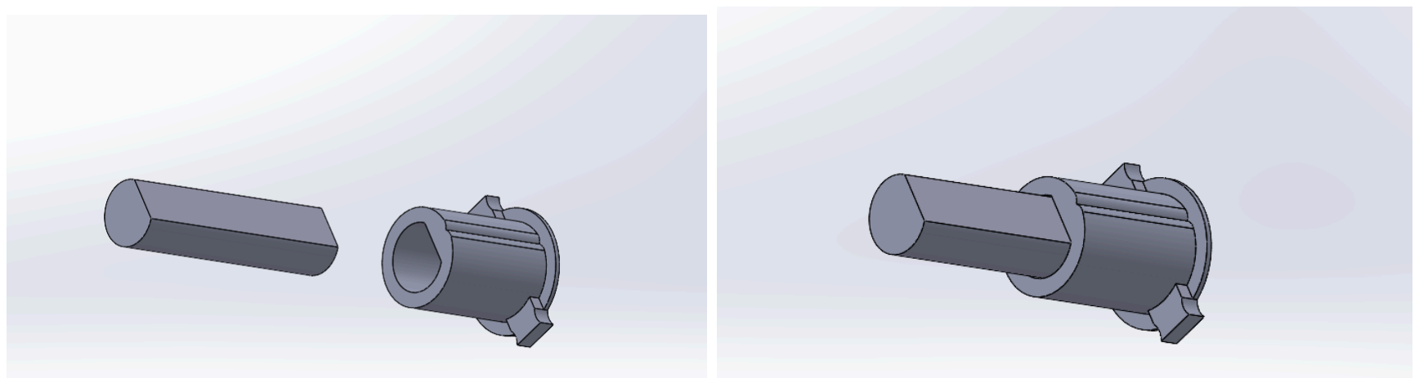
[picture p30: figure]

Step 3:
Assemble the drive shaft assembly with the planet carrier. Note that the bushing has a key. Use superglue to secure.

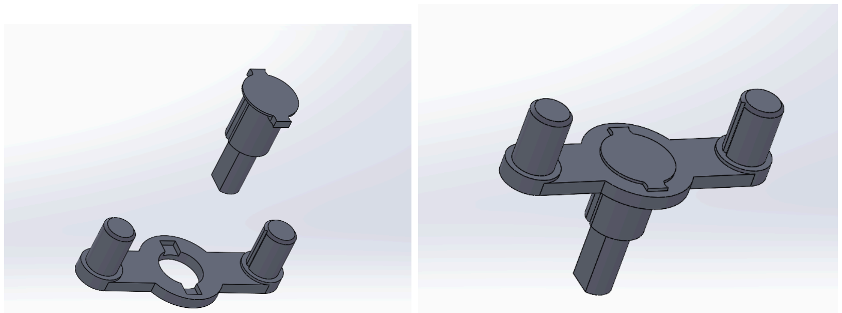
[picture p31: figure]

Step 4:
Apply silicone grease to the cylindrical surface of the drive shaft bushing and then assemble with the ring gear.

The fit should be free spinning, but as close of a fit as possible. This is the main bearing surface. It should be able to be pushed in by hand, and spun by hand after assembled

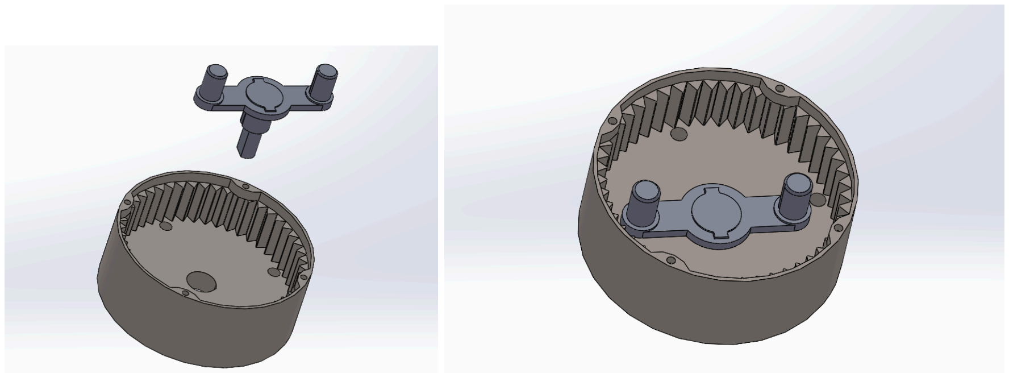
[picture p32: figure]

Step 5:
Add the planet gears onto the pins of the planet carrier. You may have to rotate the planet carrier out of the way of the cap mounting holes in order to do this.

Apply grease to the teeth of the ring gear once assembled

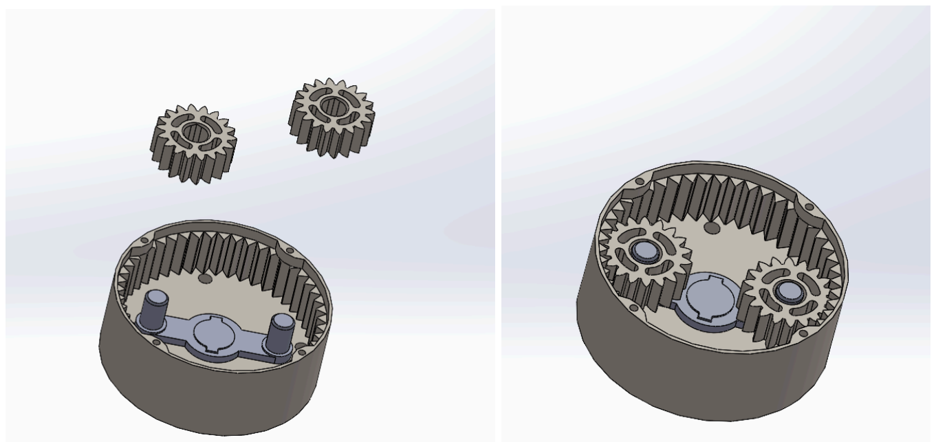
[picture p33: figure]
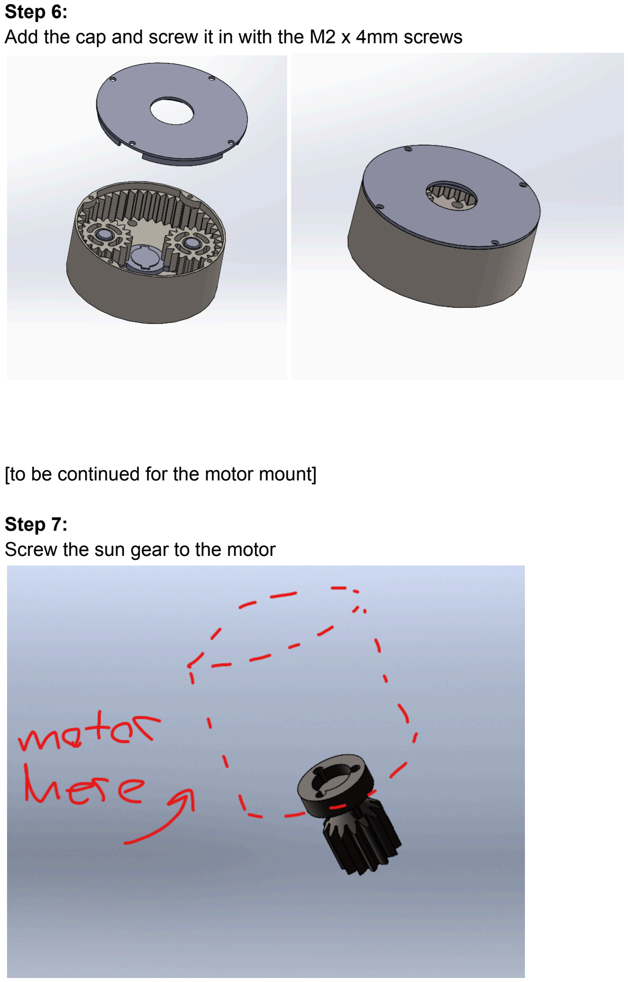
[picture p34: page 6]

Step 6:
Add the cap and screw it in with the M2 x 4mm screws

[to be continued for the motor mount]

Step 7:
Screw the sun gear to the motor

Step 8:
Screw the motor to the motor mount using the m4 screws

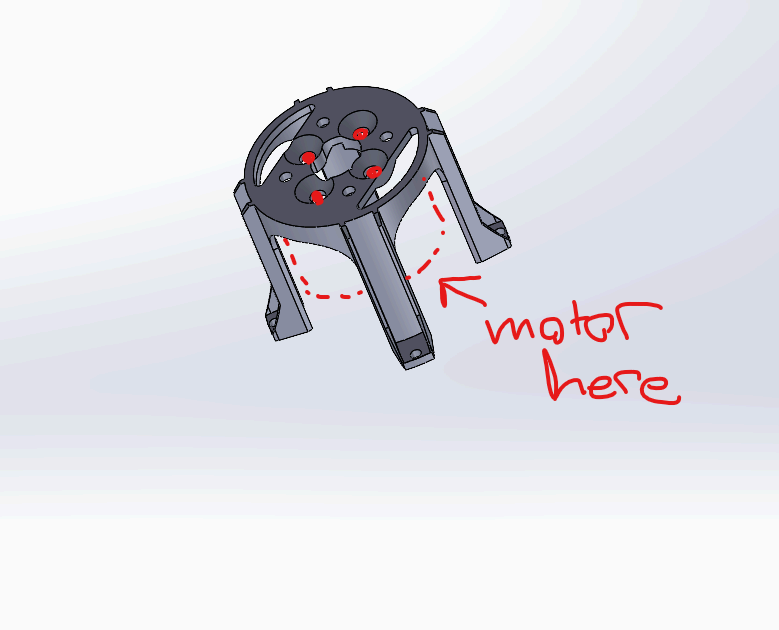
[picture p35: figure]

Step 9:
Screw the motor mount to the Ring Gear through the holes in the cap

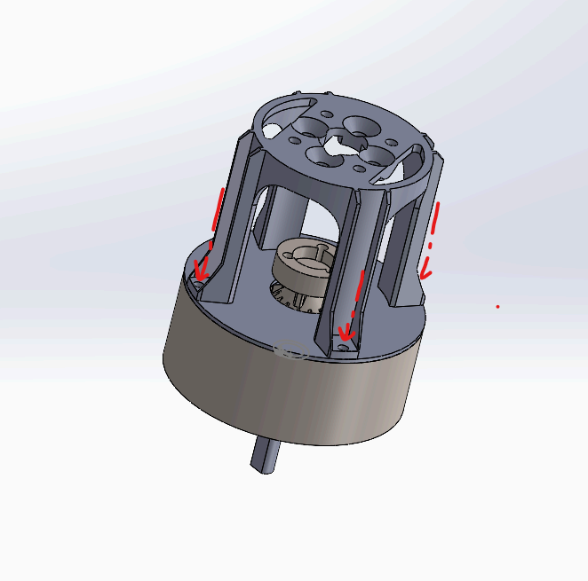
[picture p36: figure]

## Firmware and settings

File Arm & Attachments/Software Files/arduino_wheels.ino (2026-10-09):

#include "DRV8825.h"
#include "commands.h"
// For RAMPS 1.4
/*

43-1 reduction 
big wheel = 
little wheel = 15 1/2
*/

// ============ MICROSTEPPING CONFIGURATION ============
// Change this value to match your physical jumper configuration:
//   32 = 1/32 microstepping (all 3 jumpers installed) - smoother, slower, less torque
//   16 = 1/16 microstepping (MS1 + MS2 jumpers)
//    8 = 1/8  microstepping (MS1 + MS3 jumpers)
//    4 = 1/4  microstepping (only MS2 jumper) - choppier, faster, MORE TORQUE
//    2 = 1/2  microstepping (only MS1 jumper)
//    1 = full step (no jumpers)
#define MICROSTEP_MODE 32
#define STEPS_PER_REV (200 * MICROSTEP_MODE)  // 200 = standard 1.8° stepper
// =====================================================

// ============ SPEED & ACCELERATION CONFIG ============
// maxSpeed: Base RPM value. Actual speeds are 1x, 2x, 3x this value
//   - With 1/32 microstepping: try 30-60 RPM
//   - With 1/4 microstepping: can go much higher (100-200+ RPM)
#define MAX_SPEED 60

// accelInterval: Milliseconds between acceleration steps (lower = faster accel)
//   - 750 = slow/smooth acceleration (original)
//   - 200-300 = moderate acceleration
//   - 50-100 = quick acceleration
#define ACCEL_INTERVAL 750

// accelIncrement: Starting RPM increase per step
#define ACCEL_INCREMENT 5

// accelMax: Maximum RPM increase per step (caps the doubling)
#define ACCEL_MAX 20

// ================= ARM SPEED CONFIG ==================

/* Removed, because a separate arduino is needed
// effectorSpd: speed (RPM) of opening/closing end effector
#define EFFECTOR_SPD 40
// effectorEase: speed (RPM) of easing the opening/closing of the end effector
#define EFFECTOR_EASE 20
// effectorTimeFull: time (ms) for effector to move at full speed when opening/closing
#define EFFECTOR_TIME_FULL 750
// effectorTimeEase: time (ms) for effector to move at eased speed when opening/closing
#define EFFECTOR_TIME_EASE 250

// armSpd: speed (RPM) of the arm shoulder & elbow
#define ARM_SPD 20 */

// baseSpd: speed (RPM) of the arm base
#define BASE_SPD 20

// =====================================================

// back right wheel
#define X_STEP_PIN 54
#define X_DIR_PIN 55
#define X_ENABLE_PIN 38

// front right wheel
#define Y_STEP_PIN 60
#define Y_DIR_PIN 61
#define Y_ENABLE_PIN 56

// free driver (arm base)
#define Z_STEP_PIN 46
#define Z_DIR_PIN 48
#define Z_ENABLE_PIN 62

/* Removed, because a separate arduino is needed
// arm base
#define A0_STEP_PIN 43
#define A0_DIR_PIN 44
#define A0_ENABLE_PIN 45

// arm shoulder
#define A1_STEP_PIN 46
#define A1_DIR_PIN 47
#define A1_ENABLE_PIN 48

// arm elbow
#define A2_STEP_PIN 49
#define A2_DIR_PIN 50
#define A2_ENABLE_PIN 51
*/

// why are the left side wheels called "extruders"? - Lucas
// apparently it's based on the arduino pin layout - Lucas, after some research
// extruder 1 (back left wheel)
#define E0_STEP_PIN 26
#define E0_DIR_PIN 28
#define E0_ENABLE_PIN 24

// extruder 2 (front left wheel)
#define E1_STEP_PIN 36
#define E1_DIR_PIN 34
#define E1_ENABLE_PIN 30

/* Removed, because a separate arduino is needed
// switch if end effector is rotating the wrong way
#define DIR_OPEN true
*/

// switch if base is rotating the wrong way
#define DIR_CW false




/* wheel based on arduino pin position
    E1 = Front Left
    E0 = Back Left
    Y = Front Right
    X = Back Right
*/

DRV8825 backRight(X_STEP_PIN, X_DIR_PIN, X_ENABLE_PIN, STEPS_PER_REV);
DRV8825 frontRight(Y_STEP_PIN, Y_DIR_PIN, Y_ENABLE_PIN, STEPS_PER_REV);
DRV8825 frontLeft(E1_STEP_PIN, E1_DIR_PIN, E1_ENABLE_PIN, STEPS_PER_REV);
DRV8825 backLeft(E0_STEP_PIN, E0_DIR_PIN, E0_ENABLE_PIN, STEPS_PER_REV);

// Free driver (arm base): Z
DRV8825 armBase(Z_STEP_PIN, Z_DIR_PIN, Z_ENABLE_PIN, STEPS_PER_REV);

/* Removed, because a separate arduino is needed
// arm base: A0
DRV8825 armBase(A0_STEP_PIN, A0_DIR_PIN, A0_ENABLE_PIN, STEPS_PER_REV);

// arm shoulder: A1
DRV8825 armShoulder(A1_STEP_PIN, A1_DIR_PIN, A1_ENABLE_PIN, STEPS_PER_REV);

// arm elbow: A2
DRV8825 armElbow(A2_STEP_PIN, A2_DIR_PIN, A2_ENABLE_PIN, STEPS_PER_REV);
*/

byte last_command = STOP;

//long last_command_time = 0;   // ms since last command
//long command_timeout = 1000;  // ms to wait for next command before stopping

// maxSpeed uses the define from top of file
long maxSpeed = MAX_SPEED;

// The speed of the motors per side
long idle_left_speed = 1;
long idle_right_speed = 1;

long time = millis();
//long timeout = 0;
long time1 = 0;

/*// Set to current time to activate the end effector, or current time minus EFFECTOR_TIME_FULL and EFFECTOR_TIME_EASE to force stop
long timeEffectorStart = time - EFFECTOR_TIME_FULL - EFFECTOR_TIME_EASE;*/

// direction that indicates what side is going where
bool rs = false;  // right side
bool ls = false;  // left side

// global checkers for starting, stopping, and halting
int on = 0;
int stop = 0;
int halt = 0;

// variable to control slow stop/accelerate (uses define from top)
int slowSpeed = ACCEL_INCREMENT;

// indicates whether we go slow, medium, fast, or not moving with +/- for direction
int leftSpeed = 0;
int rightSpeed = 0;



void setup() {

  // use USB on serial 115200
  // I think this actually just activates the serial with a bitrate of 115200? - Lucas
  Serial.begin(115200);


  // set up the LED for ability to see if recieving commands
  pinMode(LED_BUILTIN, OUTPUT);
  digitalWrite(LED_BUILTIN, LOW);

  // right wheels front/back initial
  frontRight.set_enabled(true);
  frontRight.set_direction(false);
  frontRight.set_speed(0);

  backRight.set_enabled(true);
  backRight.set_direction(false);
  backRight.set_speed(0);

  // left wheels front/back initial
  frontLeft.set_enabled(true);
  frontLeft.set_direction(false);
  frontLeft.set_speed(0);

  backLeft.set_enabled(true);
  backLeft.set_direction(false);
  backLeft.set_speed(0);

  // arm base initial
  armBase.set_enabled(true);
  armBase.set_direction(false);
  armBase.set_speed(0);

  /* Removed, because a separate arduino is needed
  // free driver (end effector) initial
  freeDriver.set_enabled(true);
  freeDriver.set_direction(false);
  freeDriver.set_speed(0);

  // arm base/shoulder/elbow initial
  armBase.set_enabled(true);
  armBase.set_direction(false);
  armBase.set_speed(0);

  armShoulder.set_enabled(true);
  armShoulder.set_direction(false);
  armShoulder.set_speed(0);

  armElbow.set_enabled(true);
  armElbow.set_direction(false);
  armElbow.set_speed(0);*/
}

// seemingly unused variables
//long last_frequency_check_time = 0;
//long counter = 0;


void loop() {

  time1 = millis();

  read_serial();

  //checkEffectorEasing();

  // Controlls the slow start for the stepper motor checks if a certain amount of miliseconds have passed and if we want to speed up
  if (time1 - time >= ACCEL_INTERVAL && on == 1) {
    Speedup(ls, rs);
    time=time1;
  }
  // controlls the soft stop for the stepper motor checks if a certain amount of have passed and if we want to stop
  if (time1 - time >= ACCEL_INTERVAL && stop == 1) {
    Stop();
    time=time1;
  }
  // call stop function if we get stuck in a loop and it wont slow down after 2500 miliseconds
  /*if (timeout == 750) {
    stop = 1;
    on = 0;
    Stop();
  }*/

  update_motors();
}
// updates the motors
void update_motors() {

  backRight.update();
  frontRight.update();
  backLeft.update();
  frontLeft.update();

  // 2026 Team's Additions
  armBase.update();
  //armShoulder.update();
  //armElbow.update();
  //freeDriver.update();
}
// getting hung up and sending stop when we dont want to stop
// checks for commands being sent over the Serial port to the arduino/Ramps board
void read_serial() {
  if (Serial.available()) {
    
    last_command = Serial.read();
    
    // The below comments are for debugging, comment the line above and decomment the below to debug [ctrl + /]

    // String command = Serial.readStringUntil('\n');
    // if (command == "FWD")
    //   last_command = FWD;
    // if (command == "REV")
    //   last_command = REV;
    // if (command == "RIGHT")
    //   last_command = RIGHT;
    // if (command == "LEFT")
    //   last_command = LEFT;
    // if (command == "STOP")
    //   last_command = STOP;
    
    switch (last_command) {
      case STOP:
        stop = 1;
        on = 0;
        break;

      case FWD:
        if (leftSpeed >= 3 && rightSpeed >= 3)  // if we are already at max going forward do nothing
          break;
        if (leftSpeed < 3)
          leftSpeed++;
        if (rightSpeed < 3)
          rightSpeed++;
        on = 1;
        stop = 0;

        if (leftSpeed < 0)
          ls = false;
        else
          ls = true;
        if (rightSpeed < 0)
          rs = true;
        else
          rs = false;
        slowSpeed = ACCEL_INCREMENT;
        Speedup(ls, rs);

        break;
      case REV:
        if (leftSpeed <= -3 && rightSpeed <= -3)  // if we are already at max going reverse do nothing
          break;
        if (leftSpeed > -3)
          leftSpeed--;
        if (rightSpeed > -3)
          rightSpeed--;
        on = 1;
        stop = 0;

        if (leftSpeed < 0)
          ls = false;
        else
          ls = true;
        if (rightSpeed < 0)
          rs = true;
        else
          rs = false;
        slowSpeed = ACCEL_INCREMENT;
        Speedup(ls, rs);


        break;

      case RIGHT:
        if (leftSpeed >= 3 && rightSpeed <= -3)  // if we are already at max going right do nothing
          break;
        if (leftSpeed < 3)
          leftSpeed++;
        if (rightSpeed > -3)
          rightSpeed--;
        on = 1;
        stop = 0;

        if (leftSpeed < 0)
          ls = false;
        else
          ls = true;
        if (rightSpeed < 0)
          rs = true;
        else
          rs = false;
        slowSpeed = ACCEL_INCREMENT;
        Speedup(ls, rs);

        break;

      case LEFT:
        if (rightSpeed >= 3 && leftSpeed <= -3)  // if we are already at max going left do nothing
          break;
        if (rightSpeed < 3)
          rightSpeed++;
        if (leftSpeed > -3)
          leftSpeed--;
        on = 1;
        stop = 0;

        // passes in as left side , right side
        if (leftSpeed < 0)
          ls = false;
        else
          ls = true;
        if (rightSpeed < 0)
          rs = true;
        else
          rs = false;
        slowSpeed = ACCEL_INCREMENT;
        Speedup(ls, rs);


        break;
      
      // 2026 Team's Addition
      case OPEN_EFFECTOR:
        /*freeDriver.set_direction(DIR_OPEN);
        timeEffectorStart = time1;*/
        break;

      case CLOSE_EFFECTOR:
        /*freeDriver.set_direction(!DIR_OPEN);
        timeEffectorStart = time1;*/
        break;

      case STOP_EFFECTOR:
        //timeEffectorStart = time1 - EFFECTOR_TIME_FULL - EFFECTOR_TIME_EASE;
        break;

      case ARM_ROTATE_CW:
        armBase.set_direction(DIR_CW);
        armBase.set_speed(BASE_SPD);
        break;
      
      case ARM_ROTATE_CCW:
        armBase.set_direction(!DIR_CW);
        armBase.set_speed(BASE_SPD);
        break;

      case ARM_STOP_ROTATE:
        armBase.set_speed(0);
        break;

      case ARM_FWD_ELBOW:
        /*armElbow.set_direction(true);
        armElbow.set_speed(ARM_SPD);*/
        break;
      
      case ARM_REV_ELBOW:
        /*armElbow.set_direction(false);
        armElbow.set_speed(ARM_SPD);*/
        break;
      
      case ARM_STOP_ELBOW:
        //armElbow.set_speed(0);
        break;
      
      case ARM_FWD_SHOULDER:
        /*armShoulder.set_direction(true);
        armShoulder.set_speed(ARM_SPD);*/
        break;
      
      case ARM_REV_SHOULDER:
        /*armShoulder.set_direction(false);
        armShoulder.set_speed(ARM_SPD);*/
        break;
      
      case ARM_STOP_SHOULDER:
        //armShoulder.set_speed(0);
        break;

      case ARM_FWD_BOTH:
        /*armElbow.set_direction(true);
        armElbow.set_speed(ARM_SPD);
        armShoulder.set_direction(true);
        armShoulder.set_speed(ARM_SPD);*/
        break;
      
      case ARM_REV_BOTH:
        /*armElbow.set_direction(false);
        armElbow.set_speed(ARM_SPD);
        armShoulder.set_direction(false);
        armShoulder.set_speed(ARM_SPD);*/
        break;
      
      case ARM_STOP_BOTH:
        /*armElbow.set_speed(0);
        armShoulder.set_speed(0);*/
        break;

      case ARM_STOP_ALL:
        armBase.set_speed(0);
        /*armShoulder.set_speed(0);
        armElbow.set_speed(0);
        timeEffectorStart = time1 - EFFECTOR_TIME_FULL - EFFECTOR_TIME_EASE;*/
        break;

      case HALT:
        halt = 1;
        on = 0;
        frontLeft.set_speed(0);
        frontRight.set_speed(0);
        backLeft.set_speed(0);
        backRight.set_speed(0);
        armBase.set_speed(0);
        leftSpeed = 0;
        rightSpeed = 0;
        Stop();
        break;
      
      default:
        digitalWrite(LED_BUILTIN, LOW);
        stop = 1;
        on = 0;
        break;
    }
  }
}

// Adjust effector speed based on time since start of movement
void checkEffectorEasing() {
  /*if (freeDriver.get_enabled()) {
    if (time1 - timeEffectorStart < EFFECTOR_TIME_FULL) {
      freeDriver.set_speed(EFFECTOR_SPD);
    } else if (time1 - timeEffectorStart < EFFECTOR_TIME_FULL + EFFECTOR_TIME_EASE) {
      freeDriver.set_speed(EFFECTOR_EASE);
    } else {
      freeDriver.set_speed(0);
    }
  }*/
}


// Speed up function used to speed up the stepper motors from 0 to a set variable, takes in tmp as the starting variable for the speed up
void Speedup(bool left, bool right) {

  int targetSpeedL, targetSpeedR;

  // Define speed values for different modes
  const int slowSpeedValue = maxSpeed;        // Define what "slow" speed means
  const int mediumSpeedValue = maxSpeed * 2;  // Define what "medium" speed means
  const int fastSpeedValue = maxSpeed * 3;    // "Fast" is the maximum speed

  // Determine target speeds based on mode (leftSpeed and rightSpeed)
  switch (abs(leftSpeed)) {
    case 1: targetSpeedL = slowSpeedValue; break;    // Slow mode
    case 2: targetSpeedL = mediumSpeedValue; break;  // Medium mode
    case 3: targetSpeedL = fastSpeedValue; break;    // Fast mode
    default: targetSpeedL = 0; break;                // Stop or no speed
  }

  switch (abs(rightSpeed)) {
    case 1: targetSpeedR = slowSpeedValue; break;    // Slow mode
    case 2: targetSpeedR = mediumSpeedValue; break;  // Medium mode
    case 3: targetSpeedR = fastSpeedValue; break;    // Fast mode
    default: targetSpeedR = 0; break;                // Stop or no speed
  }

  // If we are moving in the opposite direction make the target negative
  if (leftSpeed < 0)
    targetSpeedL *= -1;
  if (rightSpeed < 0)
    targetSpeedR *= -1;

  // Gradually adjust left side speed
  if (idle_left_speed < targetSpeedL) {
    idle_left_speed += slowSpeed;  // Increase speed gradually
    if (idle_left_speed > targetSpeedL)
      idle_left_speed = targetSpeedL;  // Clamp to target speed
  } else if (idle_left_speed > targetSpeedL) {
    idle_left_speed -= slowSpeed;  // Decrease speed gradually
    if (idle_left_speed < targetSpeedL)
      idle_left_speed = targetSpeedL;  // Clamp to target speed
  }

  // Gradually adjust right side speed
  if (idle_right_speed < targetSpeedR) {
    idle_right_speed += slowSpeed;  // Increase speed gradually
    if (idle_right_speed > targetSpeedR)
      idle_right_speed = targetSpeedR;  // Clamp to target speed
  } else if (idle_right_speed > targetSpeedR) {
    idle_right_speed -= slowSpeed;  // Decrease speed gradually
    if (idle_right_speed < targetSpeedR)
      idle_right_speed = targetSpeedR;  // Clamp to target speed
  }

  // Check if both sides have reached their target speeds
  bool leftReached = (idle_left_speed == targetSpeedL);
  bool rightReached = (idle_right_speed == targetSpeedR);

  time = millis();

  if((idle_left_speed >= 0) == left) {
    frontLeft.set_direction(left);
    backLeft.set_direction(left);
  }
  else {
    frontLeft.set_direction(!left);
    backLeft.set_direction(!left);
  }

  if((idle_right_speed <= 0) == right) {
    backRight.set_direction(right);
    frontRight.set_direction(right);
  }
  else {
    backRight.set_direction(!right);
    frontRight.set_direction(!right);
  }


  /* 
      In the below code we need to know if we are moving in the negative direction but not set the speed to a negative value.
      Instead we multiply by -1 anytime we set a negative value. This way we are slowly changing directions and not immediately shifting over to the opposite direction. 
    */

  if ((leftReached) && (rightReached)) {
    // Both sides have reached their target speeds; set the final speed and return

    if (idle_left_speed < 0) {
      frontLeft.set_speed(-1 * targetSpeedL);
      backLeft.set_speed(-1 * targetSpeedL);
    } else {
      frontLeft.set_speed(targetSpeedL);
      backLeft.set_speed(targetSpeedL);
    }

    if (idle_right_speed < 0) {
      backRight.set_speed(-1 * targetSpeedR);
      frontRight.set_speed(-1 * targetSpeedR);
    } else {
      backRight.set_speed(targetSpeedR);
      frontRight.set_speed(targetSpeedR);
    }

    Serial.print("max reached targetL: ");
    Serial.print(targetSpeedL);
    Serial.print("   targetR: ");
    Serial.println(targetSpeedR);
    on = 0;

    slowSpeed = ACCEL_INCREMENT;  // Reset the slowSpeed for future use
    return;
  }

  // Set motor speeds
  //Serial.print("Going ils:%d    irs:%d",idle_left_speed,idle_right_speed);

  if (idle_left_speed < 0) {
    frontLeft.set_speed(-1 * idle_left_speed);
    backLeft.set_speed(-1 * idle_left_speed);
  } else {
    frontLeft.set_speed(idle_left_speed);
    backLeft.set_speed(idle_left_speed);
  }

  if (idle_right_speed < 0) {
    backRight.set_speed(-1 * idle_right_speed);
    frontRight.set_speed(-1 * idle_right_speed);
  } else {
    backRight.set_speed(idle_right_speed);
    frontRight.set_speed(idle_right_speed);
  }

  Serial.print("idleL: ");
  Serial.print(idle_left_speed);
  Serial.print("  --> ");
  Serial.println(targetSpeedL);
  Serial.print("idleR: ");
  Serial.print(idle_right_speed);
  Serial.print("  --> ");
  Serial.println(targetSpeedR);
  Serial.print("slow speed: ");
  Serial.println(slowSpeed);
  Serial.println("----------------");

  // Adjust slowSpeed for smoother acceleration
  slowSpeed = min(slowSpeed * 2, ACCEL_MAX);  // Controls the rate at which we speed up or slow down
}


// The stop function to be called to slowly stop the motors
void Stop() {
  armBase.set_speed(0);
  if (abs(idle_left_speed) <= ACCEL_INCREMENT && abs(idle_right_speed) <= ACCEL_INCREMENT) {
    idle_left_speed = 1;
    idle_right_speed = 1;
    slowSpeed = ACCEL_INCREMENT;
    stop = 0;
    leftSpeed = 0;
    rightSpeed = 0;
    backRight.set_speed(0);
    frontRight.set_speed(0);
    backLeft.set_speed(0);
    frontLeft.set_speed(0);

    Serial.println("--STOPPED--");
    return;
  }
  time = millis();
  Serial.println("Cutting speed in half...");

  idle_left_speed = idle_left_speed / 2;
  idle_right_speed = idle_right_speed / 2;

  if (idle_left_speed < 0) {
    frontLeft.set_speed(-1 * idle_left_speed);
    backLeft.set_speed(-1 * idle_left_speed);
  } else {
    frontLeft.set_speed(idle_left_speed);
    backLeft.set_speed(idle_left_speed);
  }

  if (idle_right_speed < 0) {
    backRight.set_speed(-1 * idle_right_speed);
    frontRight.set_speed(-1 * idle_right_speed);
  } else {
    backRight.set_speed(idle_right_speed);
    frontRight.set_speed(idle_right_speed);
  }
}

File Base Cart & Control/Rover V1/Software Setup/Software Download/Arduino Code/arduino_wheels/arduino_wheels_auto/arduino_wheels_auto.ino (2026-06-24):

#include "DRV8825.h"
// Autonomous Movement Version - Moves in a Square or Circle Pattern
// For RAMPS 1.4

// ============ MICROSTEPPING CONFIGURATION ============
#define MICROSTEP_MODE 32
#define STEPS_PER_REV (200 * MICROSTEP_MODE)
// =====================================================

// ============ SPEED & MOVEMENT CONFIG ============
#define MOVE_SPEED 60          // RPM for movement
#define TURN_SPEED 40          // RPM for turning (slower for accuracy)

// ============ PATTERN CONFIGURATION ============
// Set to 1 for SQUARE pattern, 0 for CIRCLE pattern
#define PATTERN_SQUARE 1

// Square pattern timing (in milliseconds)
#define FORWARD_TIME 15000      // Time to move forward (adjust for side length)
#define TURN_TIME 5000         // Time to turn 90 degrees (adjust for your rover)

// Circle pattern - differential speeds for curved path
#define CIRCLE_INNER_SPEED 30  // Inner wheel speed (slower)
#define CIRCLE_OUTER_SPEED 90  // Outer wheel speed (faster)
// =====================================================

// Motor pins for RAMPS 1.4
#define X_STEP_PIN 54
#define X_DIR_PIN 55
#define X_ENABLE_PIN 38

#define Y_STEP_PIN 60
#define Y_DIR_PIN 61
#define Y_ENABLE_PIN 56

#define Z_STEP_PIN 46
#define Z_DIR_PIN 48
#define Z_ENABLE_PIN 62

#define E0_STEP_PIN 26
#define E0_DIR_PIN 28
#define E0_ENABLE_PIN 24

#define E1_STEP_PIN 36
#define E1_DIR_PIN 34
#define E1_ENABLE_PIN 30

/* Wheel positions:
    E1 = Front Left
    E0 = Back Left
    Y = Front Right
    X = Back Right
*/

DRV8825 backRight(X_STEP_PIN, X_DIR_PIN, X_ENABLE_PIN, STEPS_PER_REV);
DRV8825 frontRight(Y_STEP_PIN, Y_DIR_PIN, Y_ENABLE_PIN, STEPS_PER_REV);
DRV8825 frontLeft(E1_STEP_PIN, E1_DIR_PIN, E1_ENABLE_PIN, STEPS_PER_REV);
DRV8825 backLeft(E0_STEP_PIN, E0_DIR_PIN, E0_ENABLE_PIN, STEPS_PER_REV);

// State machine for square pattern
enum SquareState {
  MOVE_FORWARD,
  TURN_RIGHT,
  STOPPED
};

SquareState currentState = MOVE_FORWARD;
unsigned long stateStartTime = 0;
int sideCount = 0;  // Count completed sides of the square

void setup() {
  Serial.begin(115200);
  Serial.println("Autonomous Movement Starting...");
  
  pinMode(LED_BUILTIN, OUTPUT);
  digitalWrite(LED_BUILTIN, LOW);

  // Initialize all motors
  frontRight.set_enabled(true);
  frontRight.set_direction(false);
  frontRight.set_speed(0);

  backRight.set_enabled(true);
  backRight.set_direction(false);
  backRight.set_speed(0);

  frontLeft.set_enabled(true);
  frontLeft.set_direction(false);
  frontLeft.set_speed(0);

  backLeft.set_enabled(true);
  backLeft.set_direction(false);
  backLeft.set_speed(0);

  // Wait 2 seconds before starting movement
  delay(2000);
  Serial.println("Starting autonomous movement!");
  
  stateStartTime = millis();
  
#if PATTERN_SQUARE
  Serial.println("Pattern: SQUARE");
  startForward();
#else
  Serial.println("Pattern: CIRCLE");
  startCircle();
#endif
}

void loop() {
  // Update all motors (required for stepping)
  update_motors();

#if PATTERN_SQUARE
  // Square pattern state machine
  runSquarePattern();
#else
  // Circle pattern runs continuously - nothing extra needed
  // Motors are already set to differential speeds in setup
#endif
}

// ============ MOTOR UPDATE ============
void update_motors() {
  backRight.update();
  frontRight.update();
  backLeft.update();
  frontLeft.update();
}

// ============ MOVEMENT FUNCTIONS ============

// Move forward - left wheels forward (true), right wheels forward (false)
void startForward() {
  Serial.println("Moving FORWARD");
  digitalWrite(LED_BUILTIN, HIGH);
  
  // Left side - direction true = forward
  frontLeft.set_direction(true);
  backLeft.set_direction(true);
  frontLeft.set_speed(MOVE_SPEED);
  backLeft.set_speed(MOVE_SPEED);
  
  // Right side - direction false = forward
  frontRight.set_direction(false);
  backRight.set_direction(false);
  frontRight.set_speed(MOVE_SPEED);
  backRight.set_speed(MOVE_SPEED);
}

// Turn right in place - left wheels forward, right wheels backward
void startTurnRight() {
  Serial.println("Turning RIGHT");
  digitalWrite(LED_BUILTIN, LOW);
  
  // Left side - forward
  frontLeft.set_direction(true);
  backLeft.set_direction(true);
  frontLeft.set_speed(TURN_SPEED);
  backLeft.set_speed(TURN_SPEED);
  
  // Right side - backward (opposite direction)
  frontRight.set_direction(true);
  backRight.set_direction(true);
  frontRight.set_speed(TURN_SPEED);
  backRight.set_speed(TURN_SPEED);
}

// Turn left in place - right wheels forward, left wheels backward
void startTurnLeft() {
  Serial.println("Turning LEFT");
  digitalWrite(LED_BUILTIN, LOW);
  
  // Left side - backward
  frontLeft.set_direction(false);
  backLeft.set_direction(false);
  frontLeft.set_speed(TURN_SPEED);
  backLeft.set_speed(TURN_SPEED);
  
  // Right side - forward
  frontRight.set_direction(false);
  backRight.set_direction(false);
  frontRight.set_speed(TURN_SPEED);
  backRight.set_speed(TURN_SPEED);
}

// Stop all motors
void stopMotors() {
  Serial.println("STOPPED");
  frontLeft.set_speed(0);
  backLeft.set_speed(0);
  frontRight.set_speed(0);
  backRight.set_speed(0);
}

// Circle pattern - drive in a continuous circle using differential steering
void startCircle() {
  Serial.println("Moving in CIRCLE");
  digitalWrite(LED_BUILTIN, HIGH);
  
  // Left side goes faster (outer wheel)
  frontLeft.set_direction(true);
  backLeft.set_direction(true);
  frontLeft.set_speed(CIRCLE_OUTER_SPEED);
  backLeft.set_speed(CIRCLE_OUTER_SPEED);
  
  // Right side goes slower (inner wheel)
  frontRight.set_direction(false);
  backRight.set_direction(false);
  frontRight.set_speed(CIRCLE_INNER_SPEED);
  backRight.set_speed(CIRCLE_INNER_SPEED);
}

// ============ SQUARE PATTERN STATE MACHINE ============
void runSquarePattern() {
  unsigned long currentTime = millis();
  unsigned long elapsedTime = currentTime - stateStartTime;
  
  switch (currentState) {
    case MOVE_FORWARD:
      if (elapsedTime >= FORWARD_TIME) {
        // Done moving forward, start turning
        currentState = TURN_RIGHT;
        stateStartTime = currentTime;
        startTurnRight();
      }
      break;
      
    case TURN_RIGHT:
      if (elapsedTime >= TURN_TIME) {
        // Done turning, increment side count
        sideCount++;
        Serial.print("Completed side ");
        Serial.println(sideCount);
        
        // Start moving forward again (continuous square)
        currentState = MOVE_FORWARD;
        stateStartTime = currentTime;
        startForward();
        
        // Optional: Stop after completing one full square (4 sides)
        // Uncomment the following to stop after one square:
        /*
        if (sideCount >= 4) {
          currentState = STOPPED;
          stopMotors();
          Serial.println("Square complete!");
        }
        */
      }
      break;
      
    case STOPPED:
      // Do nothing - motors are stopped
      break;
  }
}

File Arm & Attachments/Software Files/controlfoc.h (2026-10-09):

// controlfoc.h
// Hardware constants, tuning parameters, and utility prototypes for the SimpleFOC control layer.
// This is the active control header; see control.h for the legacy manual-stepping layer.
#ifndef CONTROLFOC_H
#define CONTROLFOC_H

#define POLE_PAIRS 7
#define PWM_FREQUENCY 20000          // Hz
#define SUPPLY_VOLTAGE 12.0          // volts
#define DRIVER_VOLTAGE_LIMIT 8.0       // volts
#define LOOP_DUTY_CYCLE 1000         // FOC loop iterations per main loop pass (controls CPU split between FOC and I/O)
#define LOOP_INPUT_CYCLE 10          // FOC loop iterations per serial read
#define ACCEL_RATE 0.1               // RPM per ms acceleration/deceleration rate
#define MAX_ACCEL 0.5                // max RPM change per FOC loop

// function prototypes
float radstoRPM(float rads);
float RPMtoRads(float rpm);
int clamp(int input, int min, int max);

#endif // CONTROLFOC_H

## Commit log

2026-06-23 pushing basic file structure and current robot CAD
    [Public RE-RASSOR Body V1.stl]
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2026-06-24 Fixed Base Repo
    - Added in all previous files for our robot
    - Fixed ReadMe to add proper credits
    - Added git LFS
    [Assem5.SLDASM, BLDC gear box BY_OBJECT_plate_1.3mf, BLDC gear box BY_OBJECT_plate_2.3mf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]
2026-07-02 Uploaded Basic Design for Mounting Platform and Other
    Includes:
    - DWG file
    - BAK file
    - Image of Original Design
    - Early Status Report
    Notes:
    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
    [MountingPlatform.dwg]
2026-07-03 Mounting Platform v1 Print Ready
    - Screws have been added and platform is now ready to be printed
    [MountingPlatform.dwg]
2026-07-03 Mounting Platform Print files Uploaded
    - MountingPlatform.stl: Base stl file for view
    - MountingPlatformPrint.3mf: File that will be sent to the 3D printer will all changed print settings
    [MountingPlatform.dwg, MountingPlatform.stl, MountingPlatformPrint.3mf]
2026-07-07 Mounting Platform V2 Upload
    - Increased width of mounting platforms
    - Decreased height of mounting platforms to allow for shoulder screw clearance
    - Decreased length of body to allow for shoulder plate clearance
    [MountingPlatform.dwg, MountingPlatformPrint.3mf]
2026-07-08 Printable file fixed to correct format and test printing started
    [MountingPlatformPrint.3mf, MountingPlatformPrint.gcode.3mf]
2026-07-10 V2 of Mounting Platform Complete & Ready to Print
    Includes
    - autocad dwg file for editing
    - stl for import into Bamboo Lab
    - 3mf to put on sd card for the print
    [MountingPlatform.dwg, MountingPlatform.stl, MountingPlatformPrint.gcode.3mf]
2026-07-13 End Effector Code Drafted
    - Missing controller files for previous teams' documentation
    - Edited V1 rover files to support our arm's approach
    - Drafted connections for the end effector
    Current Issues
    - Arduino.h is unfindable either a necessary source is not located within the files or a necessary download has not been documented
    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
    [arduino_wheels.ino]
2026-07-14 chore: add stls for motor and base connector
    [BLDC Arm base pivot connector.stl, BLDC Fusion Assembly.stl]
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2026-07-14 V2 of the Mounting Platform + Other
    - Printing file and stl files for Mounting Platform with addition of screws for the base
    - Configured base printing file
    - Uploaded preliminary design doc pdf to documentation
    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
    [ArmBasePrint.gcode.3mf, MountingPlatform.dwg, MountingPlatform.stl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]
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2026-07-23 feat: mock stepper based off of spec for the assembly
    [stepper.stl]
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2026-08-07 Add gripper print files and Bambu Studio Layout
    [V1GripperLayout.3mf, claw_support_BLDC_belt.stl, drive_gear.stl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]
2026-08-07 Printing Started on End Effector & Connector
    - G-Code for all components of the end effector
    - G-Code for the base pivot
    - Removed temporary organizational placeholder text files
    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
    [BaseConnectorPrint.gcode.3mf, V1GripperPrint.gcode.3mf]
2026-08-07 Organized File Structure
    - Separate g-code and CAD product subfolders
    - Removed a corrupted f3d file
    - Removed a AutoCAD backup file
    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
    [Arm Base for Stepper.f3d, Arm Base for Stepper.stl, ArmBasePrint.gcode.3mf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]
2026-08-09 Lower Main Arm Completed & Print Ready
    - stl file for component
    - dwg AutoCAD file for component
    - G-code printing file for component
    - Edited g-code for base connector
    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
    [BaseConnectorPrint.gcode.3mf, LowerMainArm.dwg, LowerMainArm.gcode.3mf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]
2026-08-09 Fix to lower main & files for lower driver
    - Reduced side of the lower are to allow for room for the arm control mechanism & saved changes to relevant files
    - STL for lower driving arm
    - DWG AutoCad file for lower driving arm
    - G-Code for lower driving arm
    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
    [LowerDriveArm.dwg, LowerDriveArm.gcode.3mf, LowerDriveArm.stl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]
2026-08-10 Constructed the connecting arms that move the upper half of the arm
    - All relevant development and printing files
    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
    [DrivingSupports.dwg, DrivingSupports.gcode.3mf, DrivingSupports.stl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]
2026-08-27 After Break Printing Updates Done on 8/26
    - Fixed G-Code to be PLA for Drive Supports, Lower Drive Arm, and Lower Main Arm
    - Fixed Lower Drive Arm's motor connection to fit snuggly
    - Printed shoulder replacement for severally damaged shoulder and replaced it on the rover
    - Printed all edited parts and assembled them.
    Needs to be Done:
    - Fix motor connection whole on pivot to be larger
    - Rewire rover's wheels (I was in the lab from 10am to around 7PM and did all the above responsibilities so this didn't get done)
    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
    [DriveSupportPrint.gcode.3mf, DrivingSupports.gcode.3mf, LowerDriveArm.dwg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]
2026-08-28 V1 of Upper Drive Arm Complete and Ready to Print
    [UpperDriveArm.dwg, UpperDriveArm.gcode.3mf, UpperDriveArm.stl]
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2026-08-30 adjust hole size for warp in print for bldc
    [BLDC Arm base pivot connector.stl]
2026-08-31 Print Files Added & Printing Started
    - Fixes to the upper drive arm printing file
    - Generation of new print file for fixes made to the base connector
    - G-code for new base component
    Tasks Starting with this Push
    - Printing of all of the above components with their subsequent manufacture
    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
    [BaseConnectorPrint.gcode.3mf, BaseStepperConnectorPrint.gcode.3mf, UpperDriveArm.gcode.3mf]
2026-08-31 Print Files for Counterweight Basket
    - G-code print file
    - DWG AutoCAD file
    - STL file for printing bed editing
    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
    [BasketCounterWeight.dwg, BasketCounterWeight.gcode.3mf, BasketCounterWeight.stl]
2026-09-01 chore: lower hole size to account for bolt being loose
    [Arm Base for Stepper.stl, Stepper To gearbox connector.stl]
2026-09-02 Updated BLDC claw support for support free printing
    [claw_support_BLDC_belt.stl]
2026-09-02 Updated gripper layout with revised BLDC claw support
    [V1GripperLayout.3mf, V1GripperPrint.gcode.3mf]
2026-09-02 Update to include static mount for driver support
    [BLDC Arm base pivot connector.stl]
2026-09-02 Basket Print Edited & Started + Misc
    - Basket print edited to include body lid while reducing overall PLA/PETG
    - Documentation file structure divided and organized to better support the project moving forward
    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
    [Arm Base for Stepper.stl, BasketCounterWeight.dwg, BasketCounterWeight.gcode.3mf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]
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2026-09-04 Redesign claws for paver pickup lips
    [left_paver_claw.stl, left_side_claw_4in_lip.stl, right_paver_claw.stl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]
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2026-09-07 Files for V2 of the Lower Main Arm
    - STL file
    - G-Code Printing File
    - DWG CAD file
    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
    [LowerMainArm.dwg, LowerMainArm.stl, LowerMainArmPrint.gcode.3mf]
2026-09-08 Fixes & Ready to Print Files for Lower Main
    - Supports to prevent screw and motor holes from warming
    - A smaller screw hole on the side opposite of the lower drive arm to prevent the motor on that side moving main substantially affecting the movement of the main arm when the drivers are in operation
    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
    [LowerMainArm.dwg, LowerMainArm.stl, LowerMainArmPrint.gcode.3mf]
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2026-09-09 Fixed the Various Printing Files
    - Proper supports readded to the Lower main arm to prevent warping in the motor holes
    - Nozzle size fix to the upper main arm
    - Fixed a file naming consistency issue
    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
    [LowerDriveArmPrint.gcode.3mf, LowerMainArmPrint.gcode.3mf, UpperDriveArm.gcode.3mf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]
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2026-09-09 Lower Main Arm Print fix
    [LowerMainArm.stl, LowerMainArmPrint.gcode.3mf]
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2026-09-11 Created Folders For V1 Version of Gripper and V2 Version of Gripper
    [V1GripperLayout.3mf, V1GripperPrint.gcode.3mf, claw_support_BLDC_belt.stl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]
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2026-09-11 Drive Supports Connectors Update
    - Divided the connector from 1 piece into 2 separate Pieces
    - Support A: the shorter of the 2 pieces. was increased by 1.5 inches to properly connect the upper and lower driving arms
    - Support B: the longer of the 2 pieces. Was increased by 3 inches to properly support full extension of the arm as previous version was far to short to match the arm's possible capabilities
    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
    [DriveSupportsPrint.gcode.3mf, DrivingSupportA.stl, DrivingSupportB.stl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]
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2026-09-11 Updated Claw Support to open up space for driven gear and new bearing retainer
    [claw_support_BLDC_belt.stl]
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2026-09-11 chore: redesign for nuts to fit under base
    [NewArmBaseForStepper.stl, NewStepperToGearboxConnector.stl]
2026-09-17 Created G-Code Printing Files for Fixed Base Components
    Note:
    - These are ready for printing and have not been started yet. They will likely be started either Thursday afternoon or prior to the team meeting Friday
    [ArmBasePrint.gcode.3mf, BaseStepperConnectorPrint.gcode.3mf]
2026-09-21 Fixed Drive Support File to Reflect Current Design
    [DriveSupportPrint.gcode.3mf, DriveSupportsPrint.gcode.3mf, DrivingSupportA.dwg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]
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2026-09-28 fix: somehow not concetric
    [New Gearbox Cap.stl]
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2026-09-30 Fixed Lower Drive Arm for Sound Connection to Moto
    [LowerDriveArm.stl, LowerDriveArmPrint.gcode.3mf]
2026-10-01 Reorganized Mechanical Folders + V2 Hand Started
    - Obsolete files moved to dev
    - Gcode separated into arm and end effector for instruction set up
    - Hand motor mount drafted and ready to print
    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
    [15TSplitPinion.stl, 30TGear.stl, ArmBasePrint.gcode.3mf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]
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2026-10-04 Full Construction of All Connectable Components
    - DWG replica of arm without nonprinted material to show concept
    - The beginnings of the motor cage
    - The motor cage needs the mechanical team to meet and agree on dimensions for our hand
    - The replica is missing some components due to connecting pieces being in dev for the base
    Kaitlyn's Side Note:
    - Assembling the replica made me wanna bang my head against the wall I now remember why I put this shit off. I hate aligning pieces so much :(
    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
    [Full Arm & Hand Assembly.dwg, MotorCage.dwg]
2026-10-05 Hand Motor System Ready for Test Printing
    - A motor cage that attaches via the back of the BLDC
    - The motor mount edited to support the cage
    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
    [Full Arm & Hand Assembly.dwg, HandMotorMount.dwg, HandMotorMount.stl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]
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2026-10-05 Hand Mount Fix 1 Attempt for Compatibility with Cage
    [HandMotorMount.dwg, HandMotorMount.stl, HandMotorMountPrint.gcode.3mf]
2026-10-06 feat: Redesign Gearbox to allow for thicken dimensions for printer
    [Gearbox Base.stl, New Gearbox Cap.stl]
2026-10-06 chore: fix dimension on mounting hole
    [Gearbox Base.stl]
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2026-10-06 Redesigned hand prongs and updated clamp
    [BottomProng.stl, ProngClamps.stl, TopProng.stl]
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2026-10-07 replace commands enum with include statmente
    [arduino_wheels.ino]
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2026-10-08 Updating Doc & PM Stuff
    - Full Hand Assembly DWG updated with current components
    - CDR uploaded to SD2 deliverables
    - ReadMe updated with current progress
    - Documentation regarding modifications to the reference hand added to misc design artifacts\
    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
    [Full Arm & Hand Assembly.dwg, HandBase.dwg]
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2026-10-09 correct number format in controlfoc.h
    [controlfoc.h]
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2026-10-09 Fix threads on worm gear
    [Worm Gear For Gripper.stl]
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2026-10-09 Fixed Components So they Line Up Correctly
    [HandBase.dwg, HandBase.stl, HandBasePrint.gcode.3mf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]
2026-10-09 remove timeout from arduino_wheels.ino and fix missing line
    [arduino_wheels.ino]
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2026-10-09 Adding halt to arduino_arm.ino and fixing stop
    [arduino_arm.ino]
2026-10-09 adding halt to arduino_wheels.ino and fixing update order
    [arduino_wheels.ino]
2026-10-09 Fix angle on prongs
    [Worm Follower For Gripper.stl]
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2026-10-25 Printable Files Reorganized in Prep for Final & Attempt At MVP Hand
    Contains: All work from Friday
    - Organization in prep for deliverables
    - Final push of hollowed middle arm components to reduce weight
    - MVP leverage attachment for case that complex hand is incompatible with resources and current design
    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
2026-10-25 Add missing halt check to arduino_wheels.ino
2026-10-25 Delete Arm & Attachments/Software Files/arduino_hand/src/DRV8825.cpp
    arduino_hand controls BLDC only and doesn't need stepper definitions
2026-10-25 Delete Arm & Attachments/Software Files/arduino_hand/src/DRV8825.h
    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
2026-10-25 Delete Arm & Attachments/Software Files/arduino_wheels/src/controlfoc.cpp
    arduino_wheels controls stepper only and doesn't need BLDC definitions
2026-10-25 Delete Arm & Attachments/Software Files/arduino_wheels/src/controlfoc.h
    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
2026-10-26 Updated gitignore + Software Bug Fix Attempts
    - A definition fix in ezrassor-service.js
    - Updated rover reachability checks with request timeouts, cancellation, and clearer connection error logging
    - Reworked the arm bridge entry point to initialize the HTTP server and configure serial communication
    - Added arm command validation and translation from controller JSON actions to Arduino command bytes
    - Tested basic command-to-byte mappings for shoulder, forearm, and end-effector actions
    - Investigated Expo startup and Android development environment issues
    What Needs Testing on Rover:
    - Basic command translation passed
    - Bridge integration and live rover connectivity remain unverifi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
2026-10-27 fix: case names
2026-10-27 fixed arduino motor control, stop handling, and firmware compatibility
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2026-10-27 Fix For MISSING Base Rotation Button
    - Button under viewport for the base
    - Command pathways to send commands to the server
    - This needs testing with the server on rover to ensure no command issues are happening but this should fix it on the UI/API section
    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
2026-10-28 Fixed Issues with Upper Drive Arm File
2026-10-28 Fixed upper drive arm again cause the prev thing I did didn't work
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2026-11-02 Documentation Files and File Naming Issue Resolved
    - Changed file names to fix pathing length issues
    - Print files for repurposed Mark 1 parts
    - Assembly image for hidden components in the overall arm dwg
    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
2026-11-05 Documentation Update
    - Current in progress assembly instructions
    - Fixed some file location issues
    - Fixed a spelling issue in a file name
    - Added Mark 1 Assembly instructions to account for reused Mark 1 parts in our project
    - Change LFS to support previously unsupported files
    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
2026-11-09 chore: ensure no tolerance on m4 screw holes
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2026-11-14 Potential Fix for Worm Gear in Gripper Issue + Updated Lower Drive and Lower Main Arm
